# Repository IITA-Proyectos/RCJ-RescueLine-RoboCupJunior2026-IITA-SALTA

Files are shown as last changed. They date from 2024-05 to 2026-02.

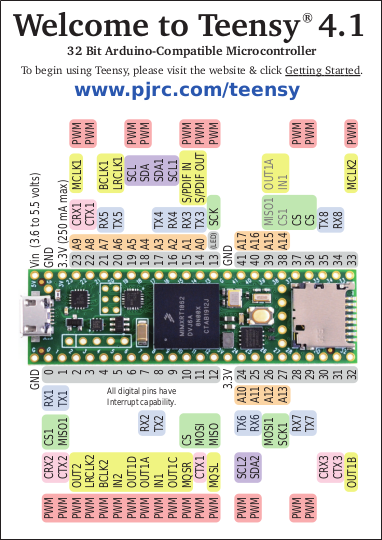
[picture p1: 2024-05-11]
Hardware/ELECTRONICA/imagenes/image.png

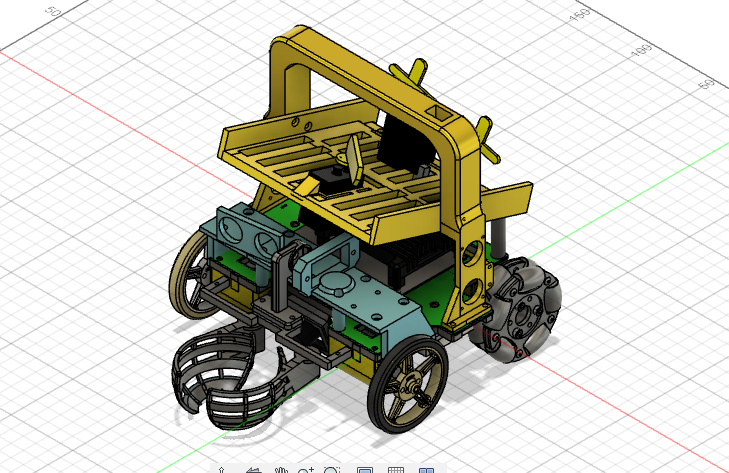
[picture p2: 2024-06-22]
Hardware/CAD/Imagenes/Rescuebot.png

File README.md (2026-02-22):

---
# Welcome to the Github account of the robotics team from IITA Salta (Argentina).
--- 
pixelcut-export (1)
## Competition info
The team is preparing for the **'Roboliga'** competition in the Rescue Line category. The Roboliga Rescue Line competition challenges teams of autonomous robots to navigate skillfully through a physical environment that simulates disaster scenarios. Equipped with sensors and programming skills, the robots must follow a line marked on rough terrain, avoiding obstacles and performing tasks such as detecting simulated victims. This competition not only tests robots' ability for autonomous navigation and environmental perception but also assesses the effectiveness of mechanical design strategies and motion control
## About us

|  |  |
|-----:|---|
|Team name | IITA SALTA- RescueBot  |
|School | Instituto de Innovacion y Tecnologia Aplicada |
|Country | Argentina |

**Mentors:**

- **Mr. Gustavo Viollaz**: 
He is the team director, and he helps with delivering or ordering the needed parts for our robot. He also gives good advice and tips on how to assemble the robot. Additionally, our director also gives us directions when needed.
- **Mr. Enzo Juarez**:
He is the team mentor and has been involved in our robotics projects for several years. He is an electronic technician, and his specialty is programming. He always helps us when we have problems.

**Members:**

- **Benjamin Villagran**:
  He is in charge of the electronics part of our robot and the programming in python.

- **Lucio Saucedo**:
  He is in charge of programming in Python and handling the Raspberry Pi integration.

- **Laureano Monteros**:
  He is in charge of programming in C++ and handling the Teensy integration.

## Our School
pixelcut-export (1)
  <p align="left">
  



  
  </p>

**Buenos Aires 135, oficina 102**

## Our Robot
All important hardware and software information and notes are stored on this Github. Use these docs as the main index:

- [Vision + YOLO](rpi/YOLO%20y%20Raspberry.md) - Pipeline de vision, modelos y reglas 2026 de rescate.
- [Raspberry <-> Teensy Communication](rpi/Comunicacion%20de%20la%20raspberry%20y%20la%20teensy.md) - Protocolo serial.
- [Pendientes (unificado)](pendientes/pendientes_generales.md) - Estado actual y tareas.

## Raspberry requirements

Instalar dependencias de Python usadas por `rpi/final_rpi/Main.py`:

```bash
pip install -r rpi/requirements.txt
```

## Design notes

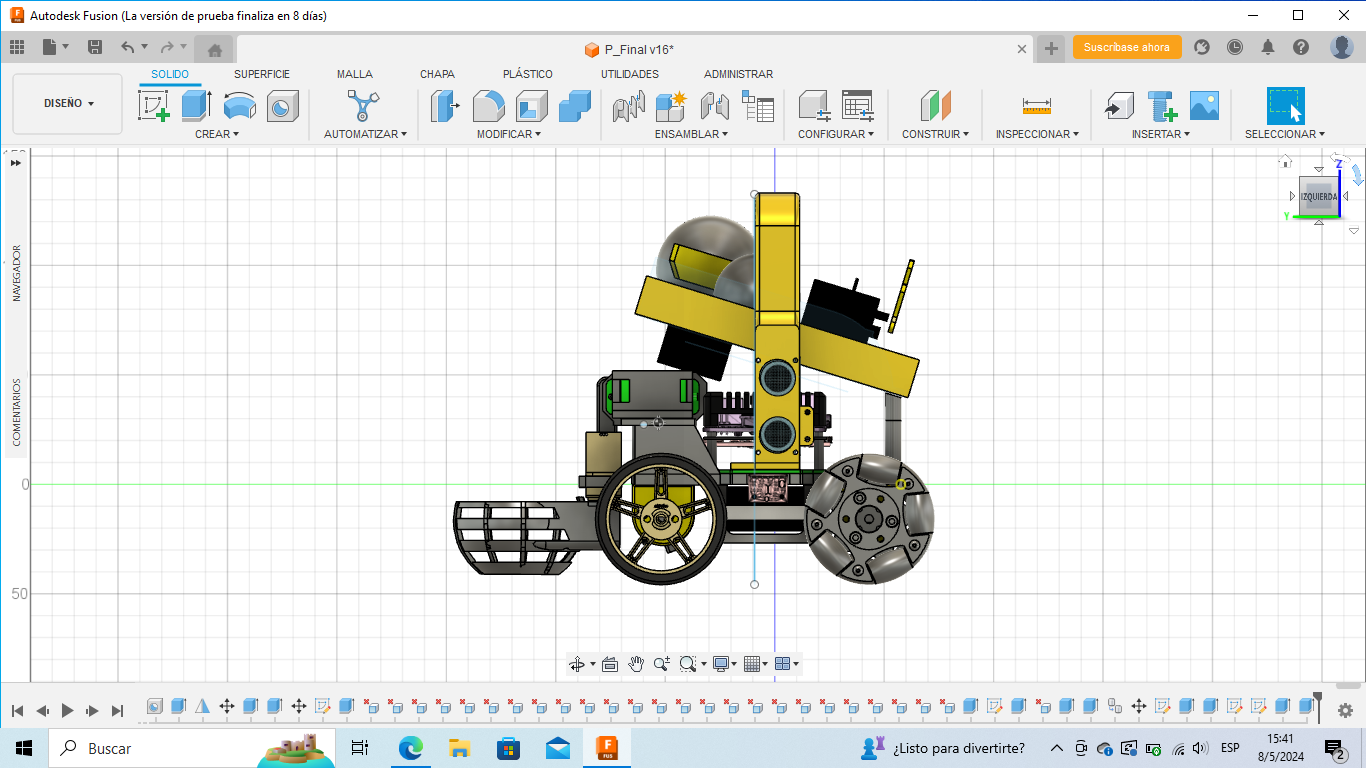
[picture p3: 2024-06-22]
Hardware/CAD/Imagenes/left.png

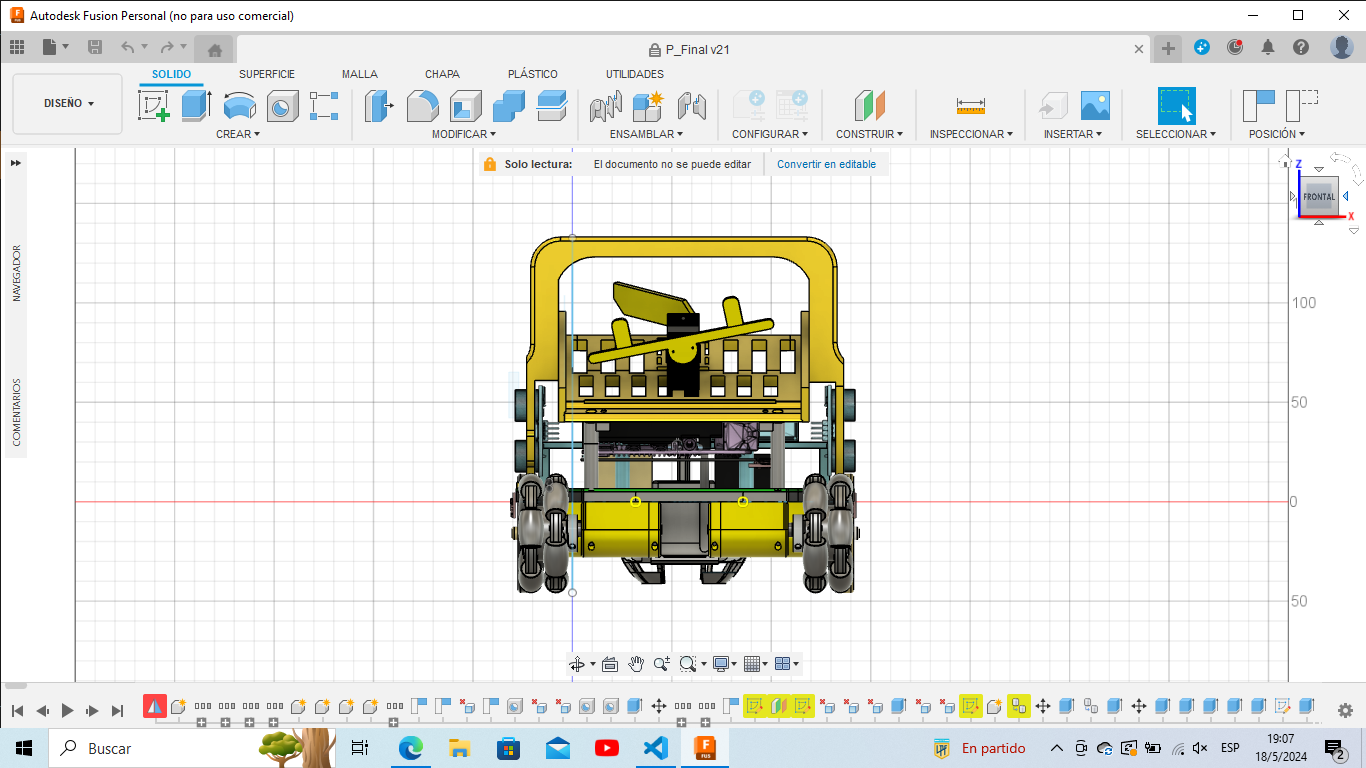
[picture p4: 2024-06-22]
Hardware/CAD/Imagenes/back.png

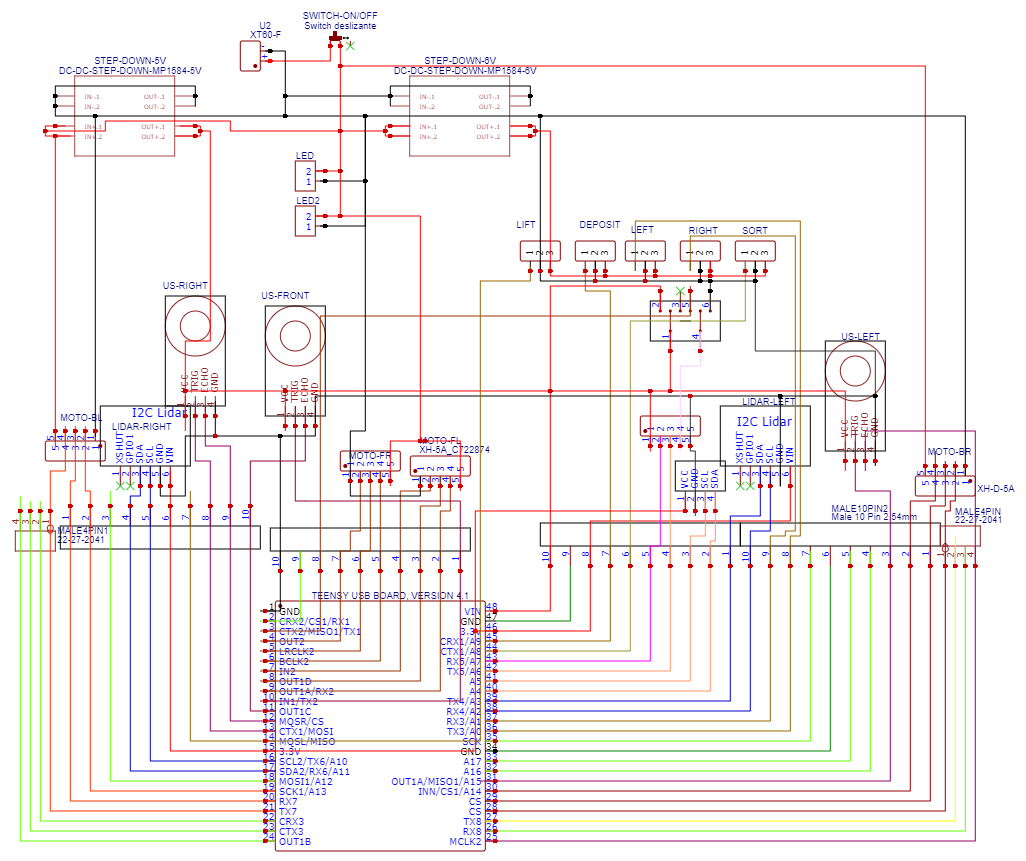
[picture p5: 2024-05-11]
Hardware/ELECTRONICA/imagenes/Schematic_Trabajo-roboliga_2024-05-02.png

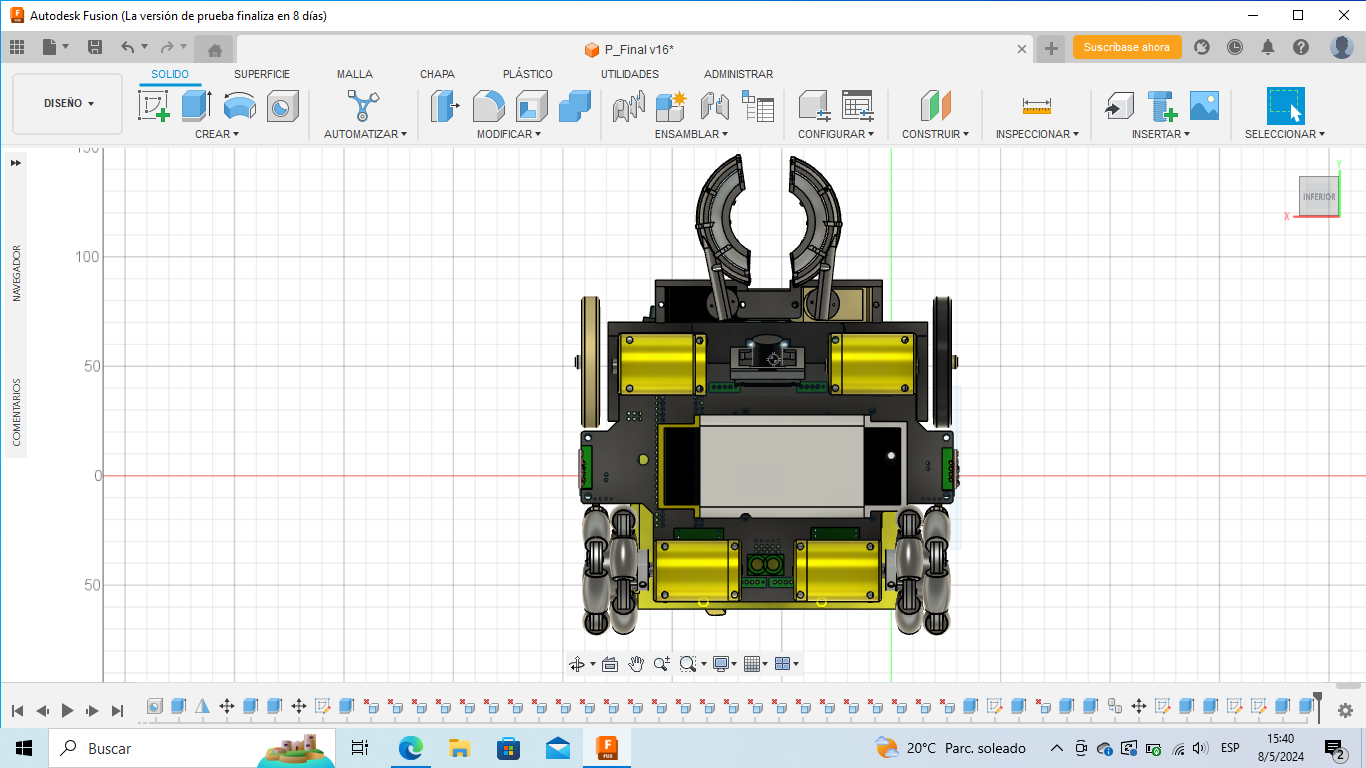
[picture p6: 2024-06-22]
Hardware/CAD/Imagenes/inferior.png

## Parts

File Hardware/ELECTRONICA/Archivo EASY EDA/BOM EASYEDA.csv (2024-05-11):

Name | Designator | Quantity
DC-DC-STEP-DOWN-MP1584-5V | STEP-DOWN-5V | 1
DC-DC-STEP-DOWN-MP1584-6V | STEP-DOWN-6V | 1
GYVL53L0X corrected | LIDAR-LEFT,LIDAR-RIGHT | 2
XH-5A_C722874 | MOTO-FL | 1
MOTO-BL | MOTO-BL | 1
XH-D-5A | MOTO-BR,MOTO-FR | 2
XT60-F | U2 | 1
Header-Female-2.54_1x3 | DEPOSIT,LEFT,LIFT,RIGHT,SORT | 5
Raspberry | RASP | 1
HUELLA_RASPBERRY_4 | U6 | 1
SOPORTE BATERIA | U7 | 1
1x2 Male Pin Header | LED,LED2 | 2
Male 10 Pin 2.54mm | MALE10PIN,MALE10PIN1,MALE10PIN2,MALE-10PIN | 4
22-27-2041 | MALE4PIN,MALE4PIN1 | 2
MPU6050 4pin | MPU6050 | 1
Toggle Switch DPDT 6 Pins 3 Positions ON/OFF/ON | SWITCH-6PIN | 1
Switch deslizante | SWITCH-ON/OFF | 1
TEENSY USB BOARD, VERSION 4.1 | U1 | 1
JSN | US-LEFT,US-RIGHT,US-FRONT | 3

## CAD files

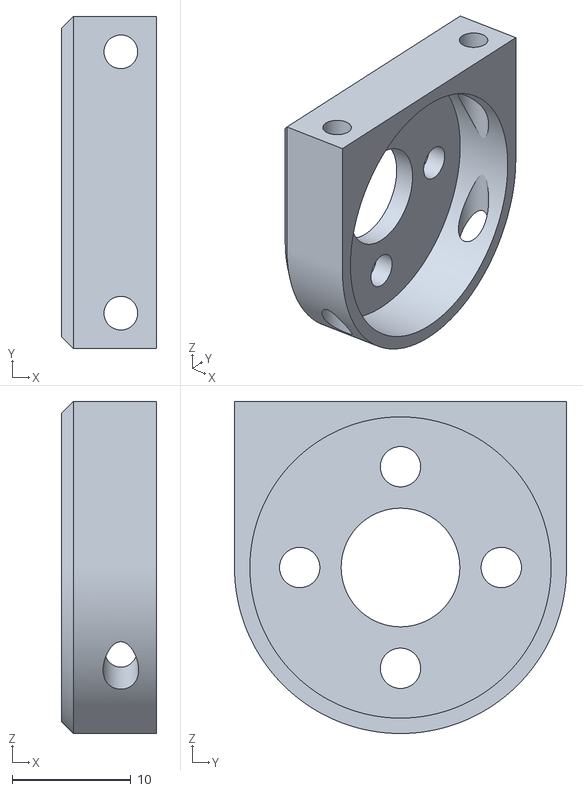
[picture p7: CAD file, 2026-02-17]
Hardware/CAD/STLS/motormount v2.stl
8.00 x 28.0 x 28.0

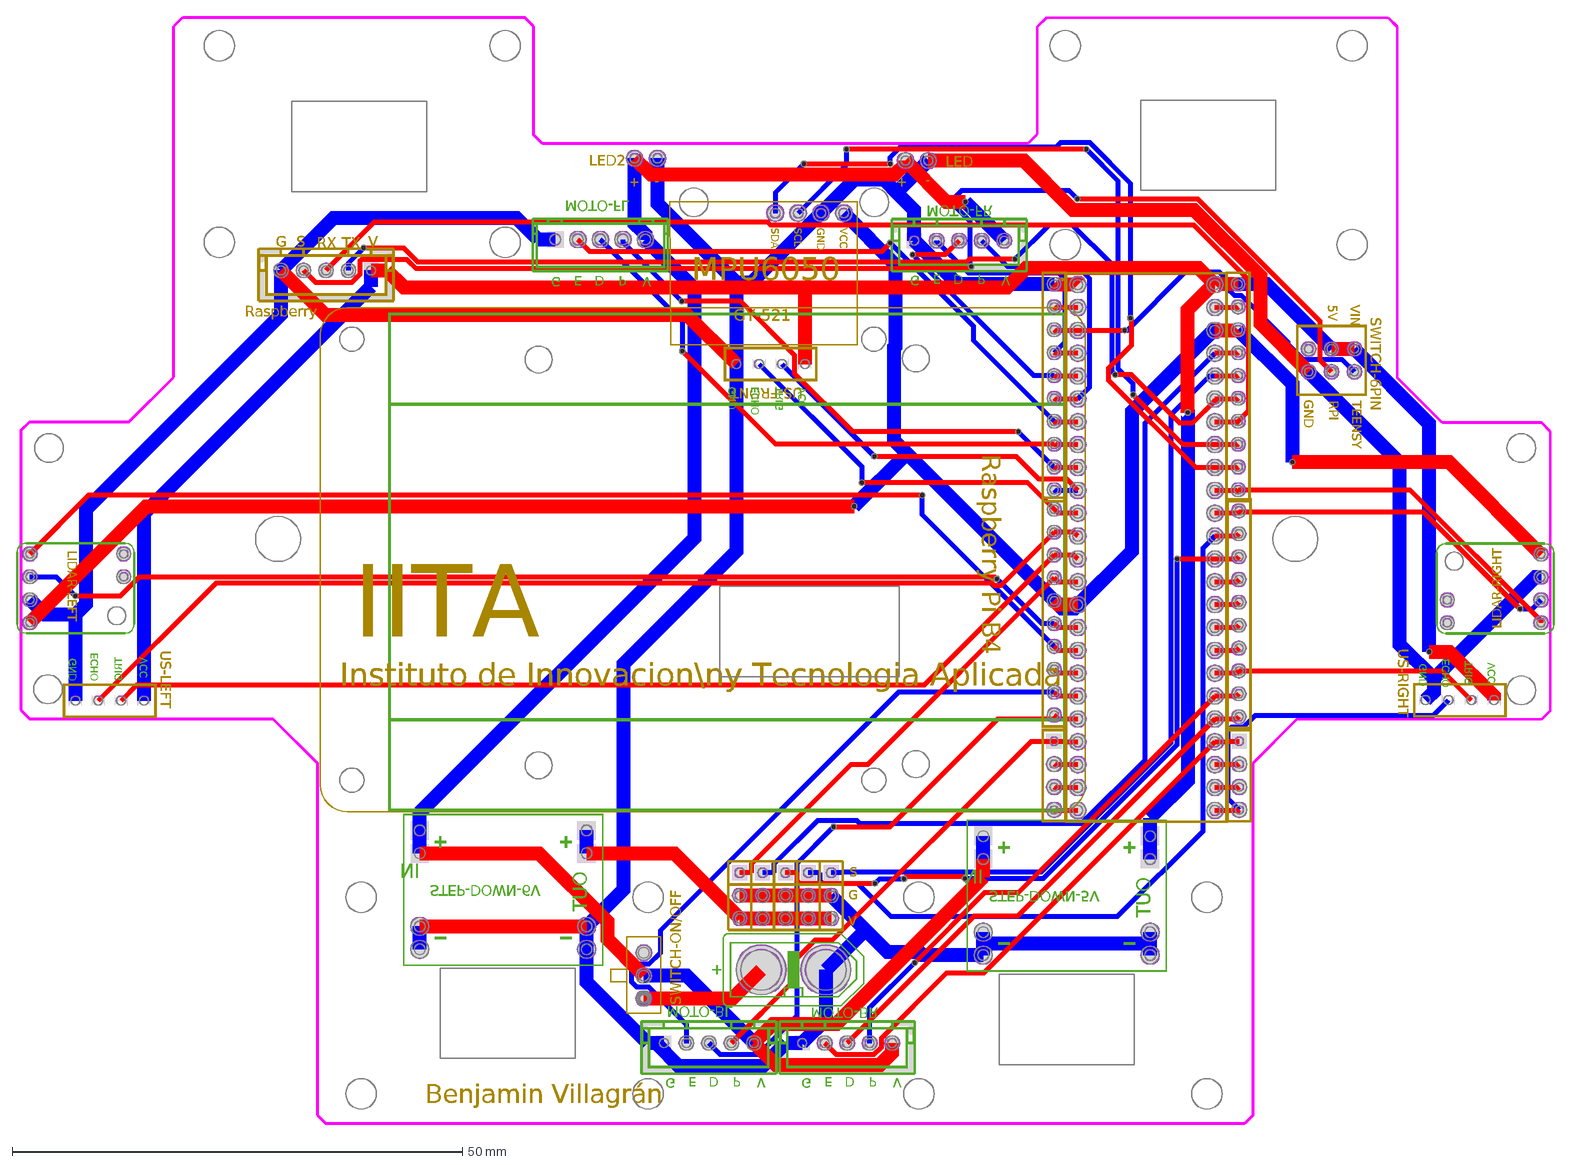
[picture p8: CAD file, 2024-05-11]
Hardware/ELECTRONICA/AUTOCAD PCB/BOCETO DE PCB.dxf
G
V
E
D
P
VIN
TEENSY
GND
RPI
5V
-
+
S
Instituto de Innovacion\ny Tecnologia Aplicada
IITA
TX
RX
Benjamin Villagrán
STEP-DOWN-5V
IN
OUT
STEP-DOWN-6V
LIDAR-LEFT
GPIO1
XSHUT
SDA
SCL
LIDAR-RIGHT
MOTO-FL
MOTO-BL
MOTO-FR
MOTO-BR
Raspberry
Raspberry Pi B4
LED
LED2
MPU6050
VCC
GY-521
SWITCH-6PIN
SWITCH-ON/OFF
US-LEFT
TRIG
ECHO
US-RIGHT
US-FRONT

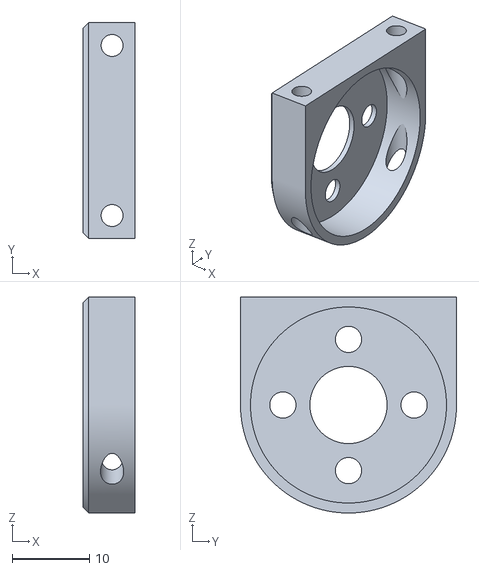
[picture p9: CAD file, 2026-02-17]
Hardware/CAD/STLS/motormount v2 thin.stl
6.80 x 28.0 x 28.0

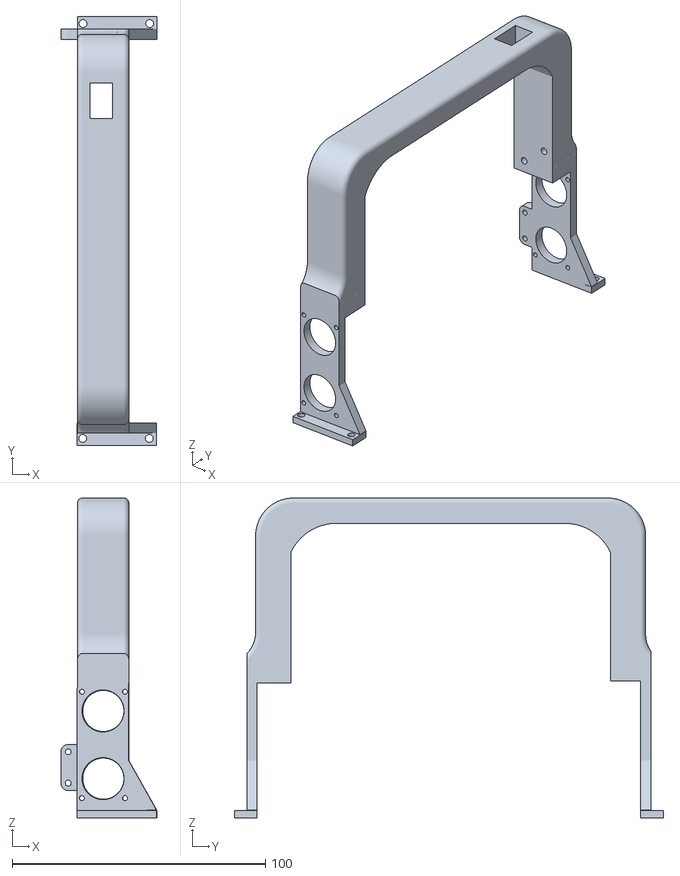
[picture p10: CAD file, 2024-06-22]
Hardware/CAD/STLS/ultrasoniDOS.stl
37.9 x 169.4 x 126.3

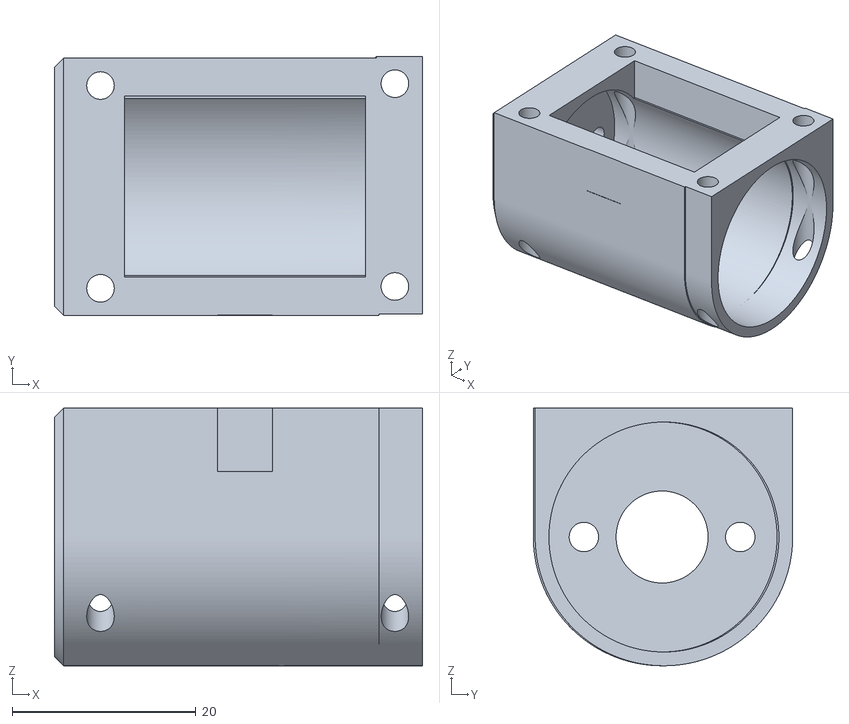
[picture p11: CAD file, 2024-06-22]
Hardware/CAD/STLS/SoporteMotorDelantero.stl
40.0 x 28.2 x 28.0

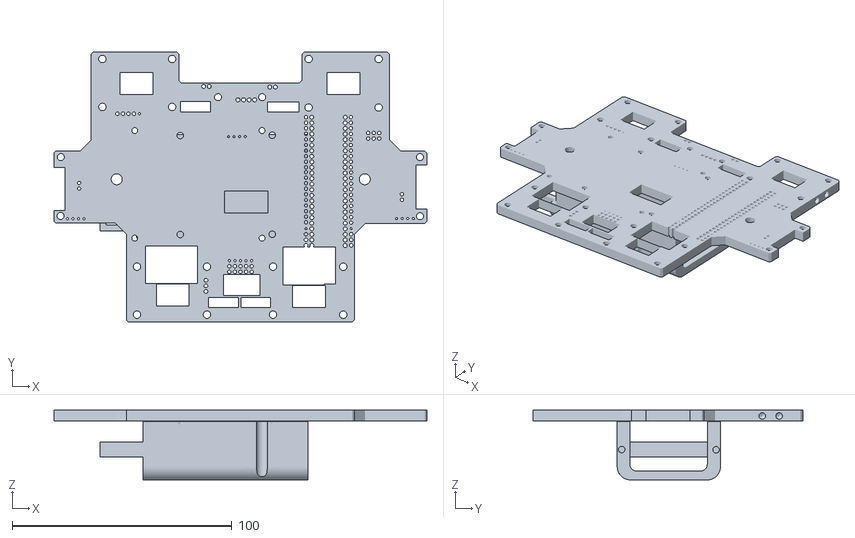
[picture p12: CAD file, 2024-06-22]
Hardware/CAD/STLS/Base.stl
169.9 x 122.9 x 31.8

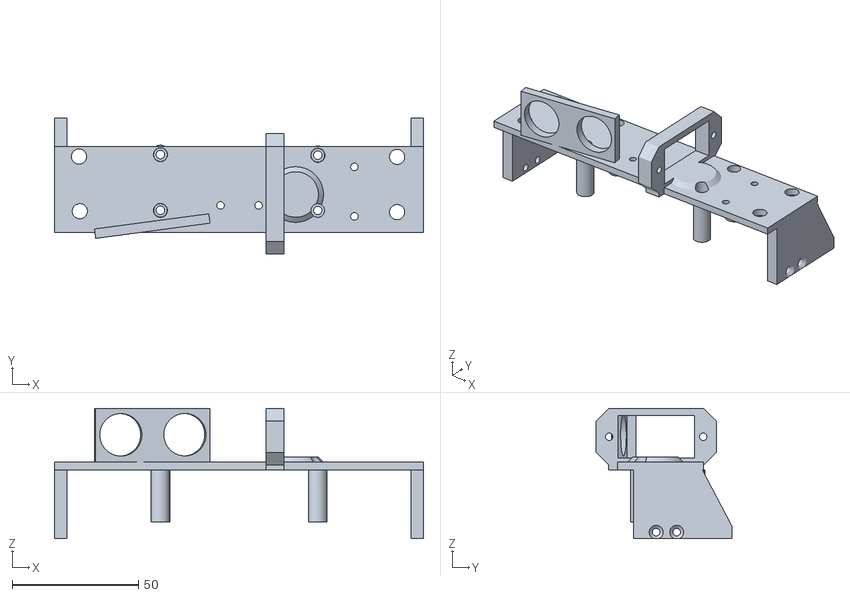
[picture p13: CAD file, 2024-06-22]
Hardware/CAD/STLS/Servos_corregido.stl
146.0 x 53.8 x 51.6

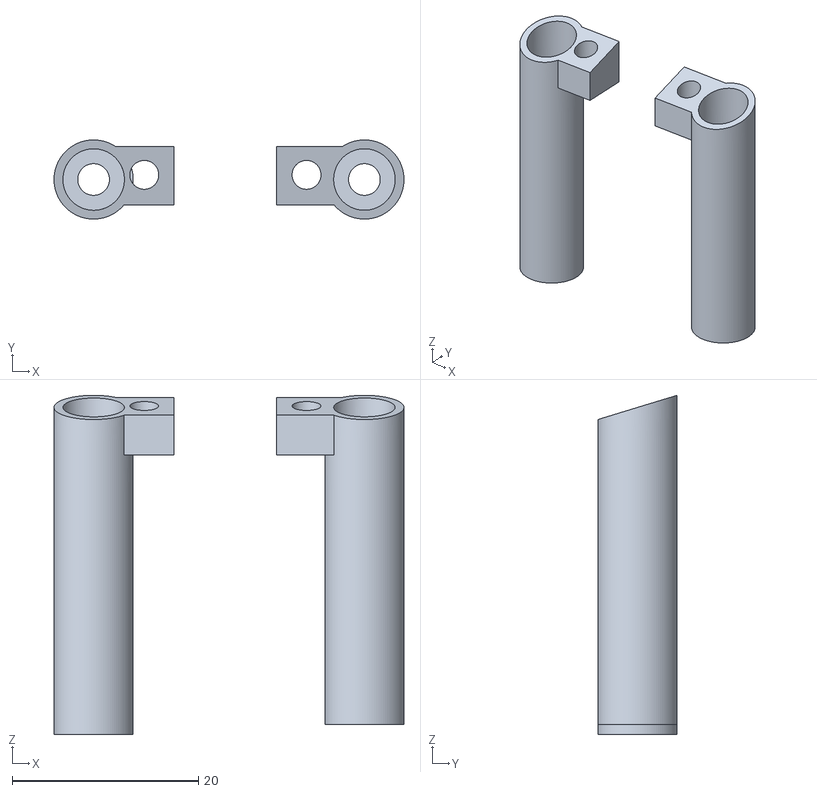
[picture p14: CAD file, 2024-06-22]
Hardware/CAD/STLS/Tubitos_juntos.stl
37.6 x 8.50 x 36.4

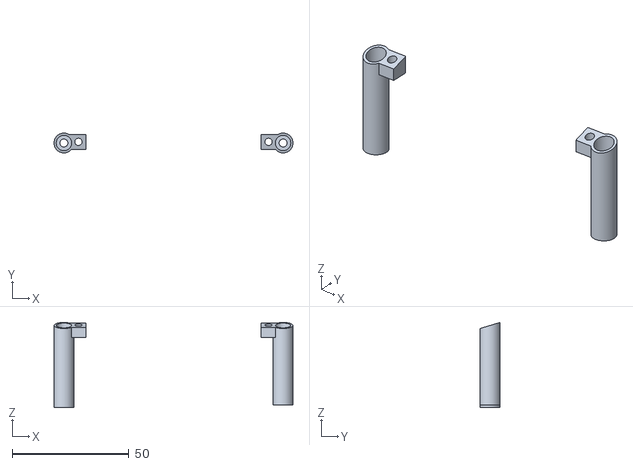
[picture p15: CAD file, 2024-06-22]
Hardware/CAD/STLS/Tubitos_6diam.stl
102.3 x 8.50 x 36.4

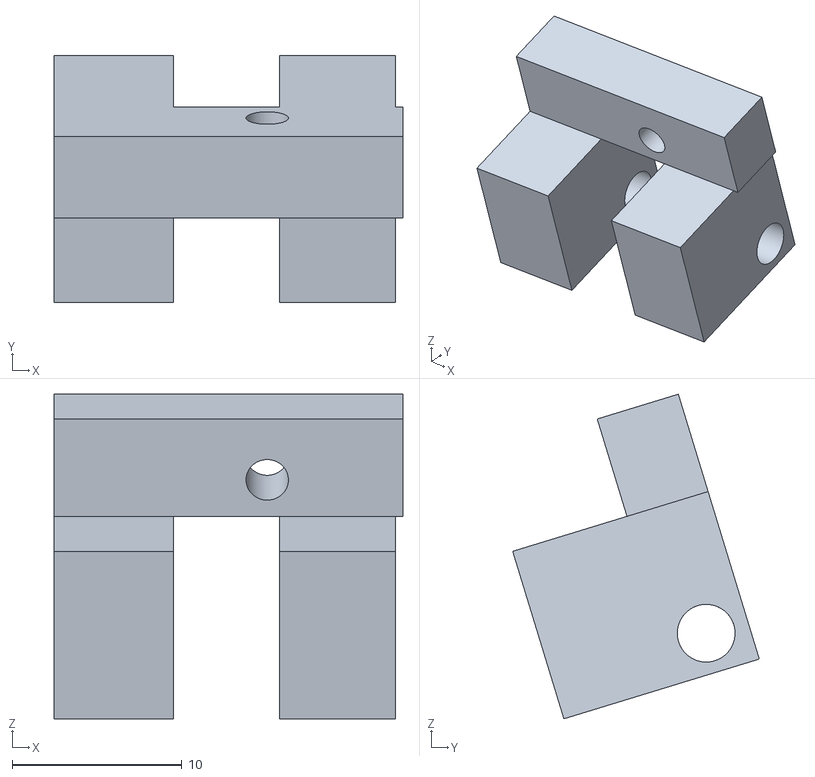
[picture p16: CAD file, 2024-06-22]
Hardware/CAD/STLS/enganche.stl
20.6 x 14.5 x 19.1

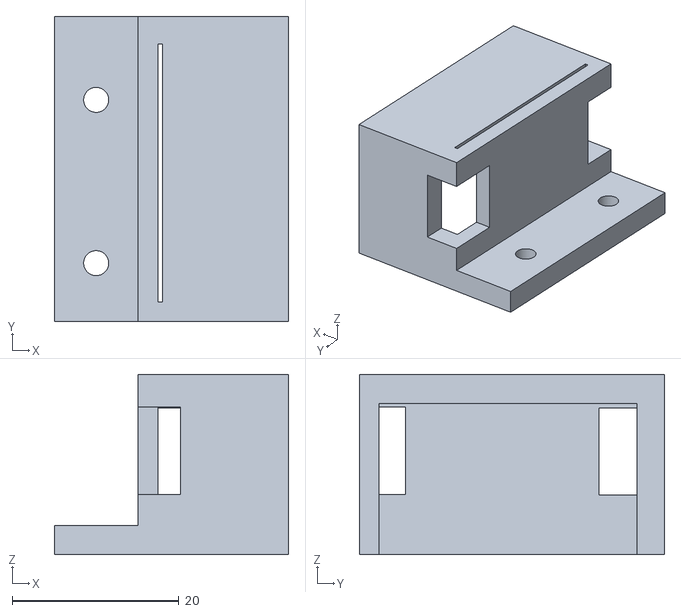
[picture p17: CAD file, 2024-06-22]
Hardware/CAD/STLS/casco de servo.stl
28.1 x 36.6 x 21.7

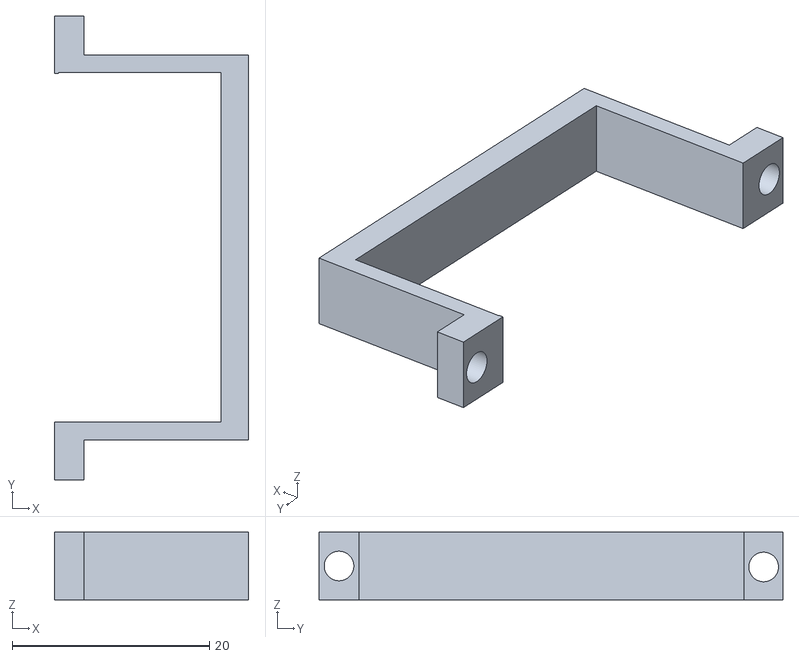
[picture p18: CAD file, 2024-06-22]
Hardware/CAD/STLS/agarra_bateria.stl
19.7 x 47.0 x 6.85

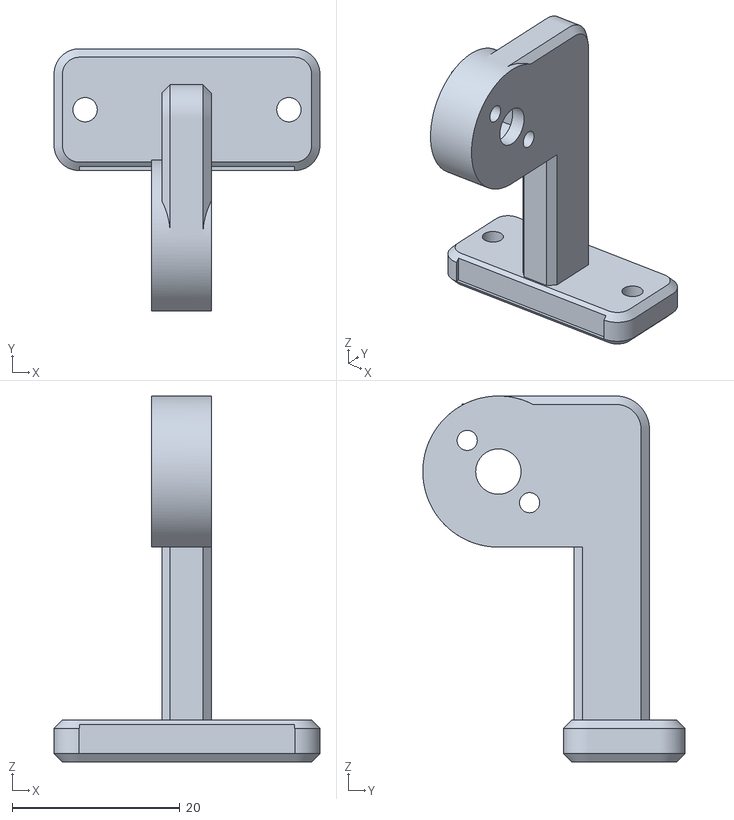
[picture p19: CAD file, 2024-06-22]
Hardware/CAD/STLS/Extensión_servo.stl
31.7 x 31.2 x 43.6

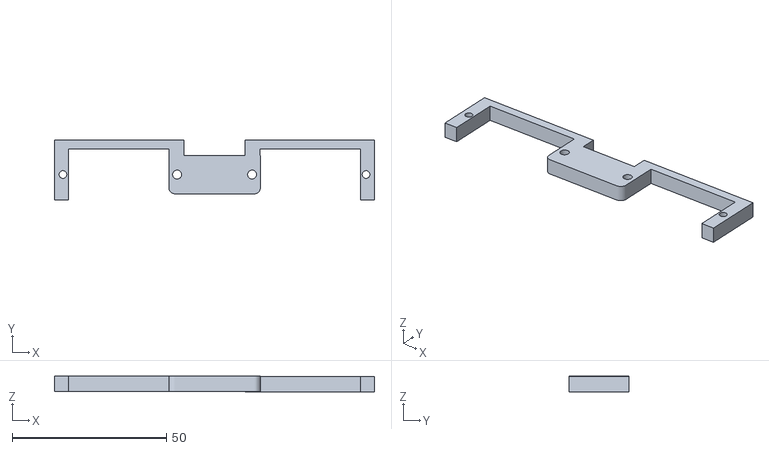
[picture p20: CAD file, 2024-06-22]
Hardware/CAD/STLS/brazo_servos.stl
103.6 x 19.5 x 5.08

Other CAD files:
Hardware/CAD/STLS/carcasa_rapsberry.stl
Hardware/CAD/STLS/Soprte-de-camara.stl
Hardware/CAD/STLS/Motor_L_corregido.stl
Hardware/CAD/STLS/BASE CAJITA.stl
Hardware/CAD/STLS/Aleta(izquierda).stl
Hardware/CAD/STLS/Aleta.stl
Hardware/CAD/STLS/controlador_pelotas.stl
Hardware/CAD/STLS/pala.stl

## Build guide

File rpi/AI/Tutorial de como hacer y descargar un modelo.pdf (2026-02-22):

## CREACIÓN MODELO ENTRENADO CON IA

En esta documentación aprenderás a crear y entrenar un modelo de inteligencia artificial (IA) desde cero para la detección de objetos. Aprenderás todo el flujo de trabajo, desde la creación del dataset, pasando por el entrenamiento del modelo, hasta su uso en código para detectar objetos en imágenes o video en tiempo real.

El objetivo de este tutorial es que, al finalizar, puedas:

- Tener un dataset correctamente anotado y preprocesado.
- Entrenar un modelo de detección de objetos utilizando Roboflow
- Descargar el modelo entrenado y usarlo en tus proyectos, por ejemplo en robots o sistemas de visión.

¿Qué es Roboflow?

Roboflow es una plataforma en la nube que permite a a crear, organizar y entrenar datasets de manera fácil. Con Roboflow se pueden:

- Subir imágenes y anotarlas para tareas
de detección de objetos, clasificación o
segmentación.
- Exportar el dataset en formatos compatibles con frameworks populares como YOLO, TensorFlow, PyTorch y ONNX.
- Entrenar modelos directamente en la
nube o descargar el dataset para

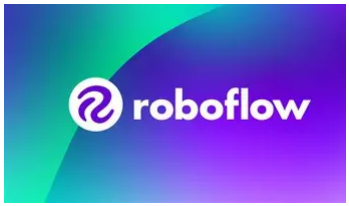
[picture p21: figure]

entrenarlo localmente (es lo que vamos a hacer)

### Creación y entrenamiento de un modelo con Roboflow

Paso 1: Crear un proyecto en Roboflow

1. Ingresar a Roboflow y registrarse.
2. Hacer clic en “Create New Project”.
3. Seleccionar tipo de proyecto: Object Detection.
4. Poner un nombre al proyecto (por ejemplo: Roboliga 2025).
5. Elegir el formato de anotación (YOLO, COCO, etc.) y crear el proyecto.

Paso 2: Subir imágenes y etiquetar

1. Hacer clic en “Upload Images” dentro del proyecto.
2. Seleccionar las imágenes del dataset.
3. Asignar las clases o labels (por ejemplo: boxgreen, boxred, negro, plateado).
4. Revisar que los bounding boxes estén correctamente colocados.

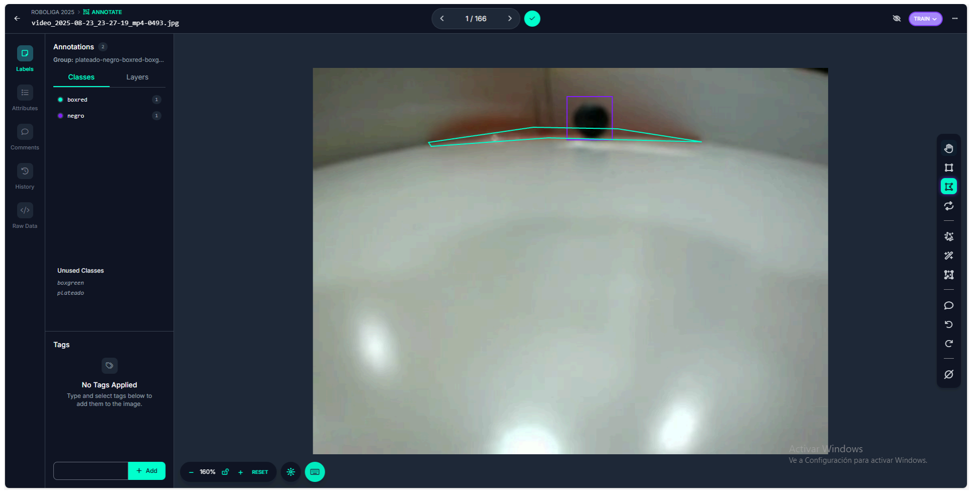
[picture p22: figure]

Paso 3: Generar dataset listo para entrenamiento

1. Dentro del proyecto, hacer clic en la opción indicada (la flecha en la imagen).

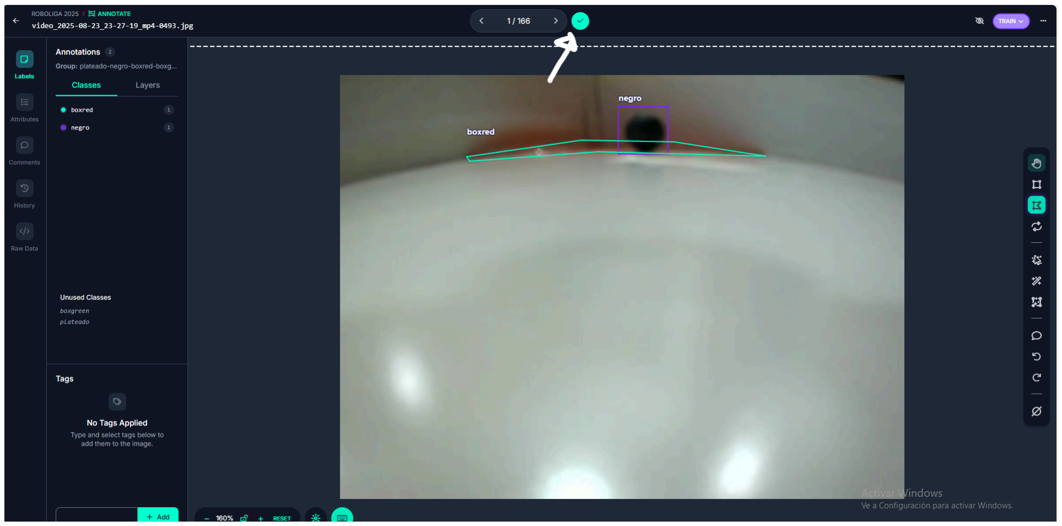
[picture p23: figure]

2. Esto añadirá al dataset final todas las imágenes que previamente revisaste y etiquetaste, garantizando que estén listas para el entrenamiento.

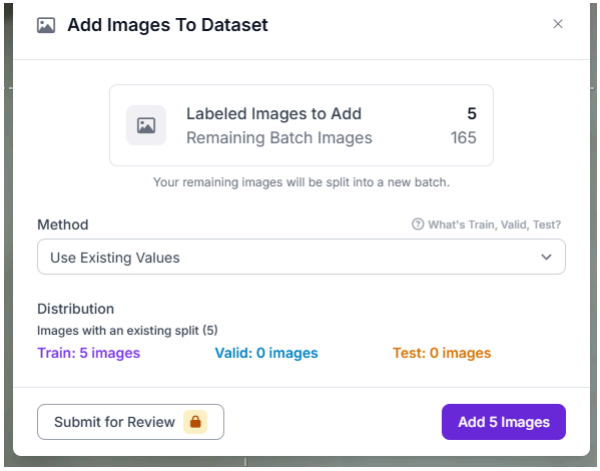
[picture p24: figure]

Paso 4: Entrenamiento en Roboflow

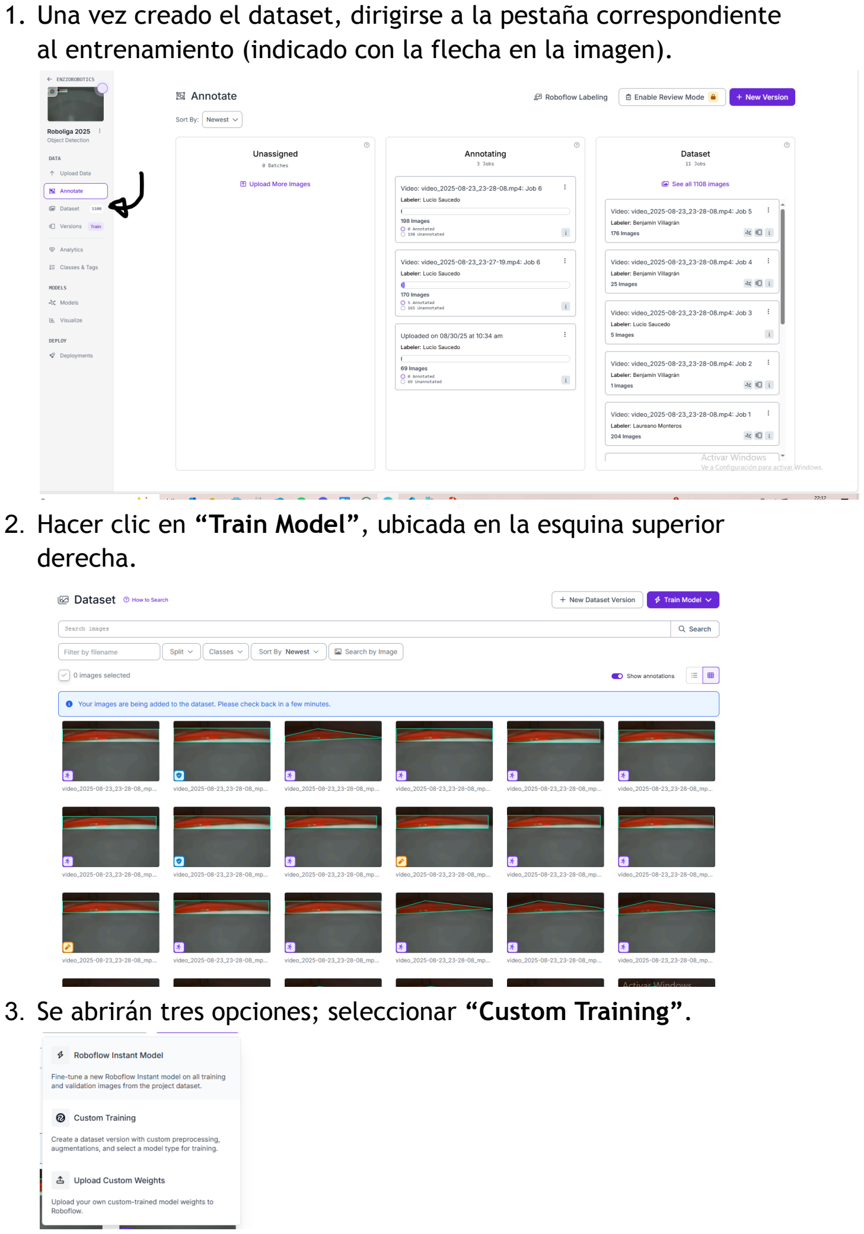
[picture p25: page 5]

1. Una vez creado el dataset, dirigirse a la pestaña correspondiente al entrenamiento (indicado con la flecha en la imagen).
2. Hacer clic en “Train Model”, ubicada en la esquina superior derecha.
3. Se abrirán tres opciones; seleccionar “Custom Training”.

4.Asignar un nombre a la versión del modelo que se va a crear.

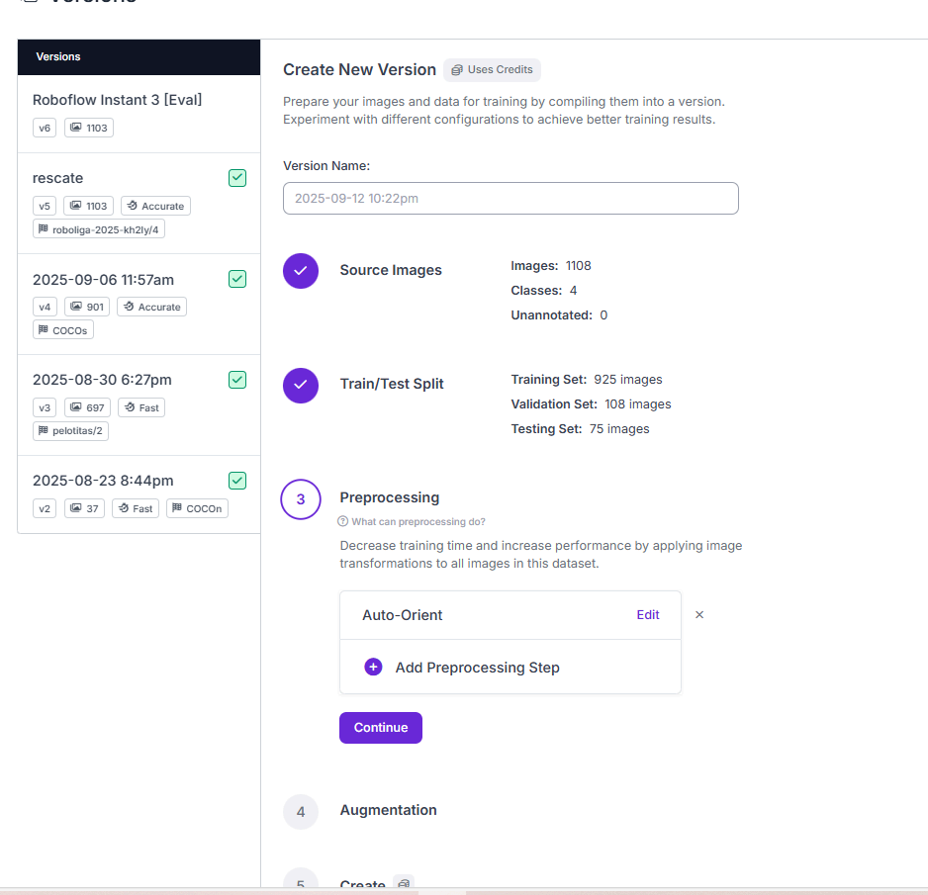
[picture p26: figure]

5. Seguir el asistente y hacer clic en “Continuar” hasta crear la versión del modelo.

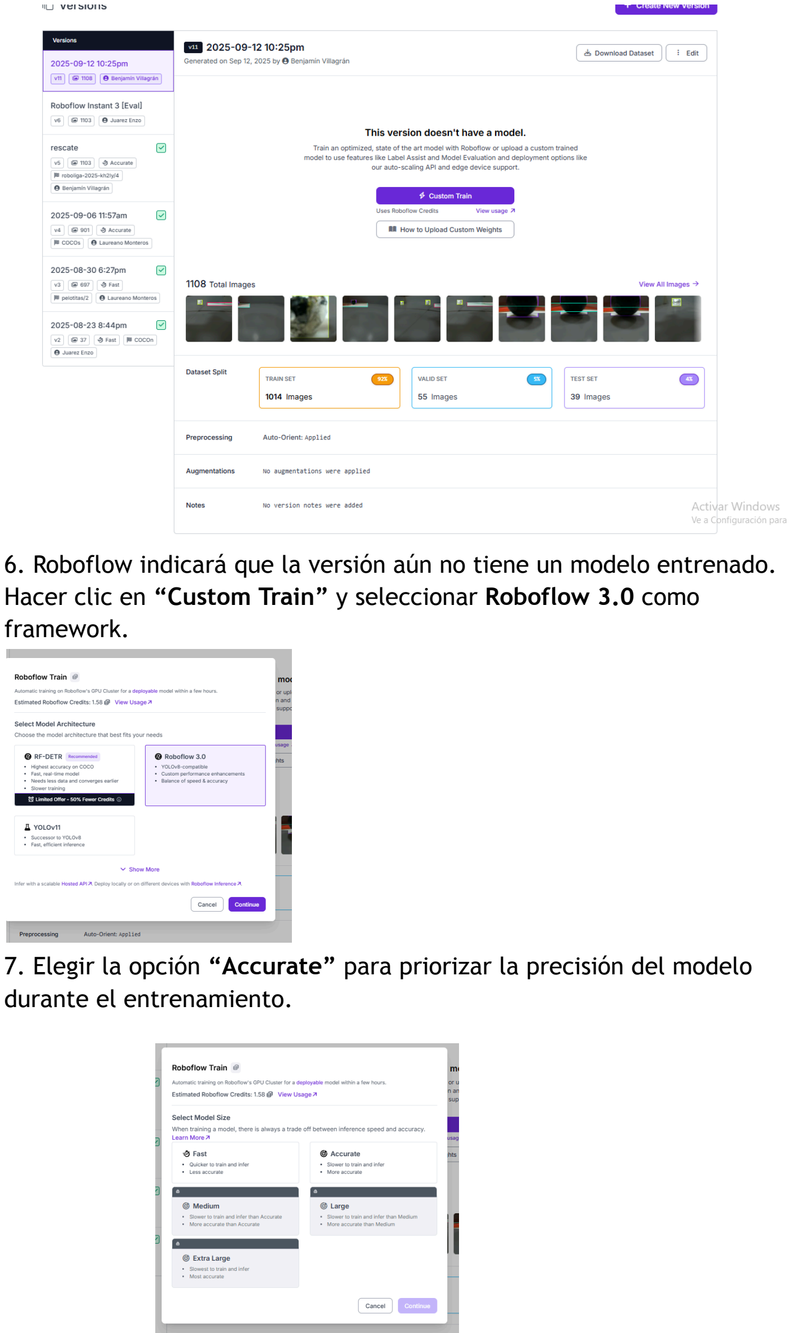
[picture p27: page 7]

6. Roboflow indicará que la versión aún no tiene un modelo entrenado. Hacer clic en “Custom Train” y seleccionar Roboflow 3.0 como framework.
7. Elegir la opción “Accurate” para priorizar la precisión del modelo durante el entrenamiento.

8.Tras configurar los parámetros, Roboflow comenzará a entrenar el dataset. El tiempo de entrenamiento dependerá del tamaño del dataset y de los recursos de la nube disponibles.

9.Una vez finalizado, dirigirse a la sección “Versions” para visualizar el modelo entrenado.

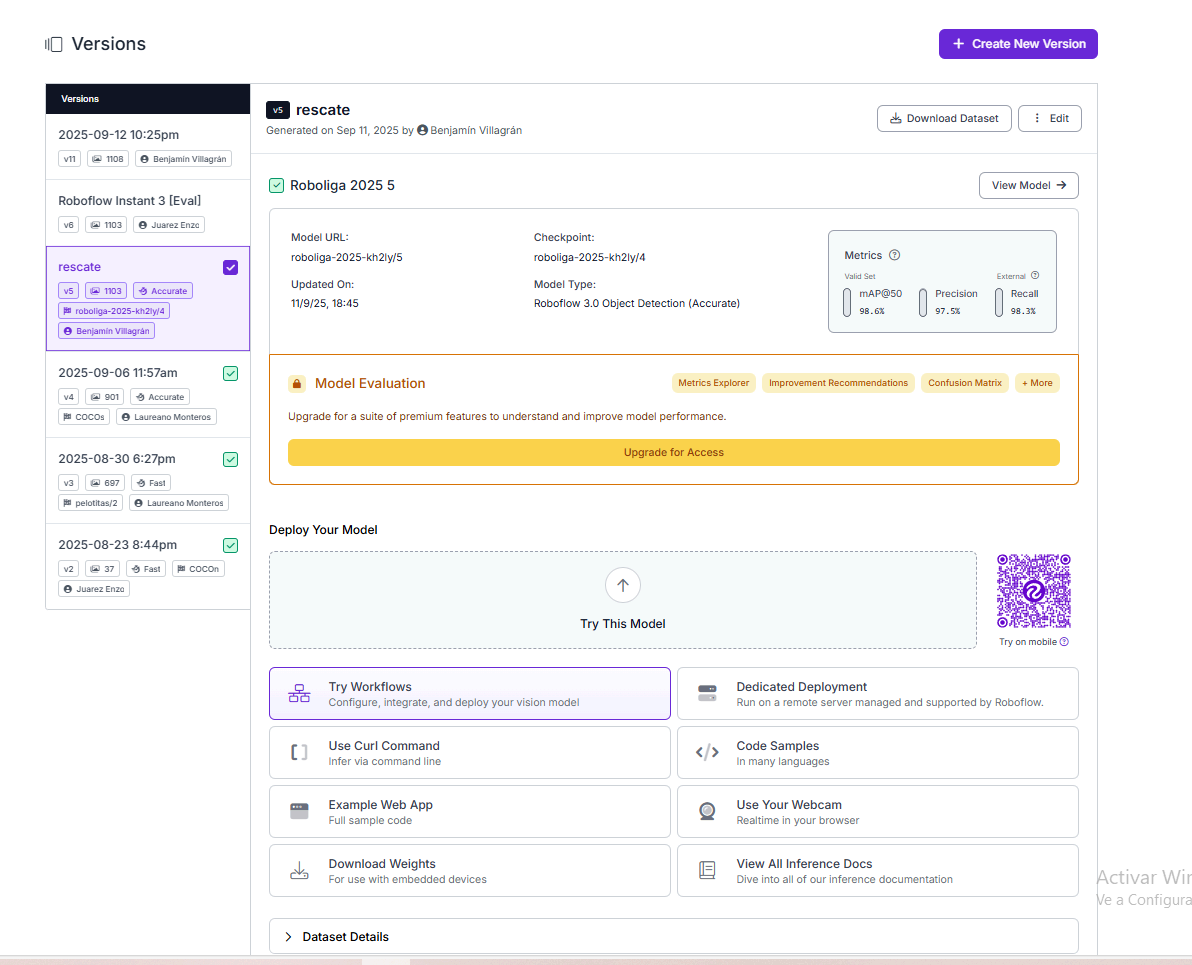
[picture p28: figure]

Nota: Roboflow no permite descargar el modelo entrenado de forma gratuita.

Para continuar trabajando localmente, se puede descargar el dataset con todas las anotaciones ya realizadas.
10. Hacer clic en “Download Dataset” y seguir el asistente haciendo clic en “Continuar”.

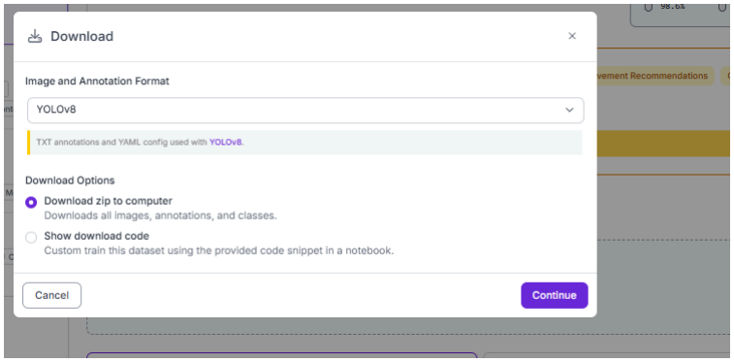
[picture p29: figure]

11. Esto permitirá usar el dataset para entrenar el modelo localmente con cualquier framework compatible, como YOLOv8 o PyTorch.

### Entrenamiento en Google Colab

Después de haber creado y preparado nuestro dataset en Roboflow, ahora vamos a dar el siguiente paso: entrenar nuestro modelo de detección de objetos utilizando Google Colab.

En esta etapa aprenderemos a:

1. Cargar el dataset descargado de Roboflow en Colab, que ya contiene todas las imágenes y etiquetas revisadas.
2. Configurar el entorno de entrenamiento, incluyendo la instalación de librerías necesarias como ultralytics.
3. Entrenar el modelo de manera sencilla y guiada.
4. Evaluar y guardar el modelo entrenado, listo para usarlo en proyectos locales, robots o aplicaciones de visión por

computadora.

Esta etapa aprovecha la potencia de procesamiento de Colab para entrenar modelos de manera eficiente, incluso si tu computadora local no tiene GPU.

### ¿Qué es Google Colab?

Google Colab (Colaboratory) es una plataforma gratuita de Google que permite escribir y ejecutar código en Python directamente desde el navegador, sin necesidad de instalar nada en tu computadora.

Sus principales ventajas son:

- Uso de GPU y TPU gratuitas: Ideal para entrenar modelos de inteligencia artificial y redes neuronales sin depender de la potencia de tu computadora local.
- Entorno en la nube:
Todos los archivos y
proyectos se pueden
guardar en Google
Drive, lo que facilita
acceder y compartir
los proyectos desde
cualquier lugar.
- Integración con
librerías de IA y
visión por
computadora: Se

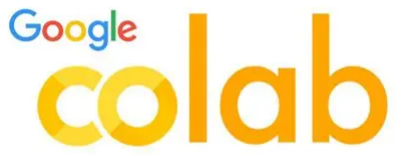
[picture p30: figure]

pueden instalar y usar frameworks como YOLOv8, TensorFlow, PyTorch, OpenCV, entre otros.

- Ideal para principiantes y profesionales: Permite experimentar con proyectos de IA sin necesidad de configuraciones complejas.

En este tutorial utilizaremos Colab para entrenar nuestro modelo de detección de objetos usando el dataset previamente creado en Roboflow, aprovechando su GPU para un entrenamiento rápido y eficiente.

### Tutorial: Entrenamiento del modelo en Google Colab

Paso 1: Abrir Google Colab

1. Ingresar a Google Colab. (http://colab.research.google.com)
2. Hacer clic en “Nuevo cuaderno” (New Notebook) para crear un proyecto vacío donde trabajaremos nuestro entrenamiento.

Paso 2: Configurar la GPU

1. Ir al menú “Entorno de ejecución” → “Cambiar tipo de entorno de ejecución”.

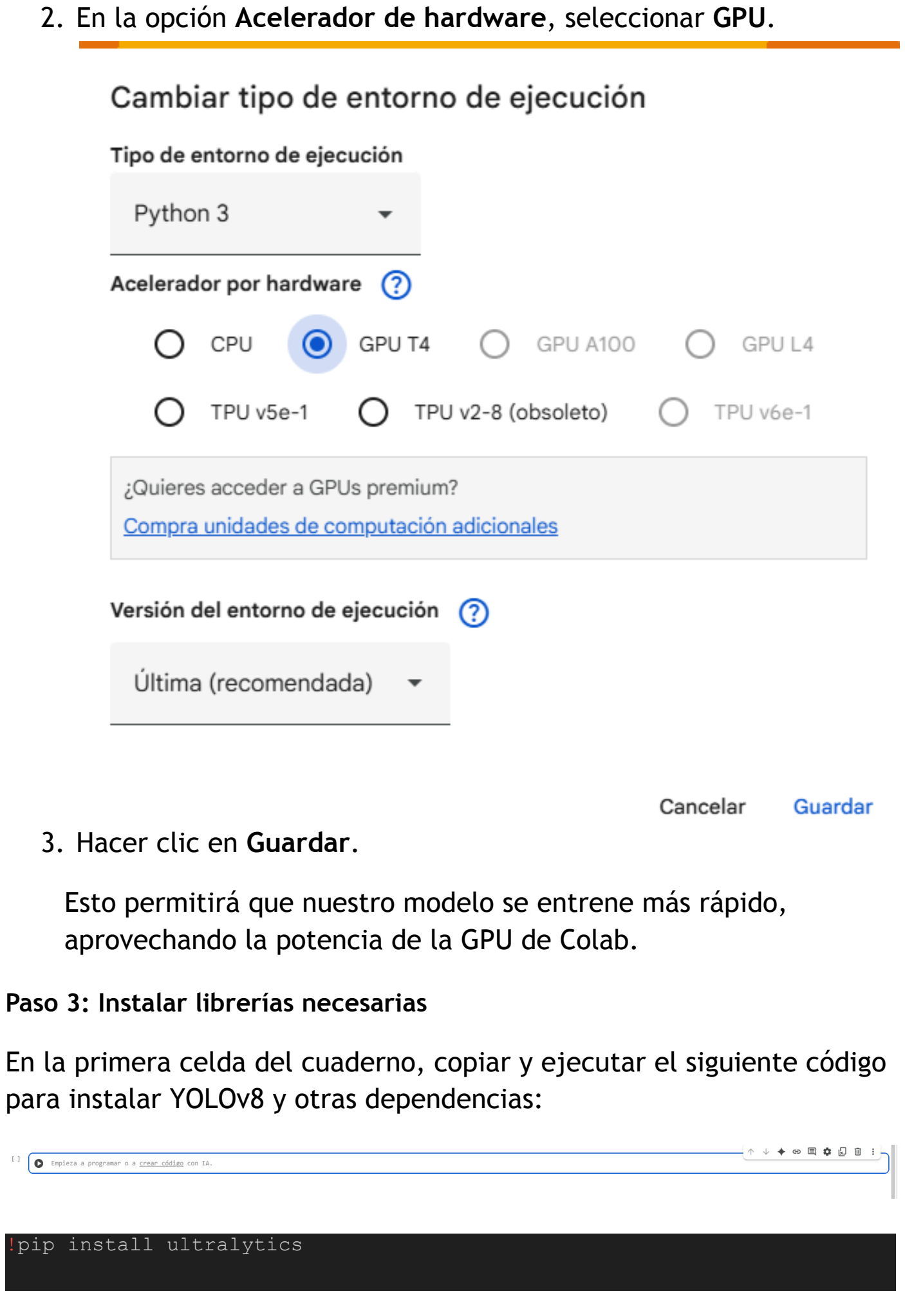
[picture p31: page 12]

2. En la opción Acelerador de hardware, seleccionar GPU.
3. Hacer clic en Guardar.

Esto permitirá que nuestro modelo se entrene más rápido, aprovechando la potencia de la GPU de Colab.

Paso 3: Instalar librerías necesarias

En la primera celda del cuaderno, copiar y ejecutar el siguiente código para instalar YOLOv8 y otras dependencias:

!pip install ultralytics

Esto instalará todo lo necesario para trabajar con nuestro dataset y entrenar el modelo.

Paso 4: Cargar y extraer el dataset en Google Colab

1. Subir el archivo ZIP de tu dataset descargado de Roboflow:

from google.colab import files

# Aparecerá un botón para seleccionar tu archivo ZIP

files.upload()

2. Una vez subido, extraer el contenido del ZIP a la carpeta dataset:

!unzip dataset.zip -d dataset

Esto creará una carpeta llamada dataset con todas las imágenes y etiquetas listas para entrenar el modelo.

Paso 5: Entrenar el modelo

from ultralytics import YOLO

# Cargar un modelo YOLOv8 base (ej. yolov8n.pt)

model = YOLO("yolov8n.pt")

# Entrenar el modelo usando el dataset extraído

model.train(data="dataset/data.yaml", epochs=50)

Asegúrate de que dentro del ZIP exista el archivo data.yaml que indica las rutas de imágenes y etiquetas. Ten en cuenta que si no seleccionaste la opcion de GPU tardara horas en cambio si la seleccionaste tardara mucho menos tiempo

Paso 6: Descargar y probar el modelo entrenado

1. Una vez finalizado el entrenamiento, el modelo se guarda automáticamente en:

runs/detect/train/weights/best.pt

2. Para descargarlo a tu computadora, ejecutar en Colab:

from google.colab import files

files.download("runs/detect/train/weights/best.pt")

Esto abrirá un cuadro de diálogo para guardar el archivo.

3. Este archivo .pt contiene el modelo entrenado y puede ser usado para:
- Inferencia en tu computadora local.
- Integración en un robot o proyecto de visión por computadora.
- Exportarlo a otros formatos (ONNX, CoreML, etc.) si lo necesitás.

### Consideraciones para Raspberry Pi

El archivo .pt que descargamos contiene el modelo completo entrenado y funciona muy bien en una computadora con GPU potente.

Sin embargo, en una Raspberry Pi:

- La potencia de procesamiento es limitada.
- El modelo .pt puede ser muy pesado y generar baja velocidad de inferencia.
- Esto puede causar que el robot o la aplicación se vuelva lenta o no pueda procesar video en tiempo real.

Solución:
Para usar el modelo en dispositivos con recursos limitados, como la Raspberry Pi, es recomendable convertirlo a un formato más ligero, por ejemplo:
- ONNX (.onnx): Permite usar el modelo con librerías optimizadas para ARM.

En el próximo paso veremos cómo exportar nuestro modelo .pt a ONNX, lo que permitirá ejecutar la detección en la Raspberry Pi de manera más eficiente.

### Paso 7: Exportar el modelo a ONNX para Raspberry

Pi

Para que nuestro modelo funcione de manera eficiente en dispositivos con recursos limitados como la Raspberry Pi, lo convertiremos a ONNX, un formato más ligero y compatible con frameworks optimizados para ARM.

### 1. Exportar el modelo entrenado

Después de entrenar tu modelo y tener best.pt, ejecuta la siguiente celda en Colab:

from ultralytics import YOLO

# Cargar el modelo entrenado

model = YOLO("runs/detect/train/weights/best.pt")

# Exportar a ONNX

model.export(format="onnx")

Esto creará un archivo best.onnx en la misma carpeta donde se encuentra tu .pt.

### 2. Descargar el modelo ONNX a tu computadora

from google.colab import files

# Descargar el archivo ONNX

files.download("runs/detect/train/weights/best.onnx")

Ahora tienes tu modelo en formato ONNX, listo para ser transferido a la Raspberry Pi.

### Probando el modelo en la Raspberry Pi

Una vez que hayas descargado tu modelo entrenado (.onnx) desde Google Colab, ya estás listo para probarlo en tu Raspberry Pi.

### 1. Instalar librerías necesarias

Antes de ejecutar el código, asegúrate de tener estas librerías instaladas en tu Raspberry Pi:

sudo apt update

sudo apt install -y python3-pip libatlas-base-dev

pip3 install --upgrade pip

pip3 install ultralytics numpy

pip3 install opencv-python

### 2. Código de ejemplo para probar el modelo

import cv2
import numpy as np from ultralytics import YOLO

# ---- CONFIG ----

MODEL_PATH = "/home/pi/Desktop/roboliga.onnx" # ruta de tu modelo VIDEO_PATH = 0 # 0 = cámara por defecto, o ruta de un video SCORE_THRESHOLD = 0.4
CLASS_NAMES = ['boxgreen', 'boxred', 'negro', 'plateado']

# ---- cargar modelo ----

model = YOLO(MODEL_PATH)
print("Modelo cargado correctamente.")

# ---- abrir cámara o video ----

cap = cv2.VideoCapture(VIDEO_PATH)
if not cap.isOpened():
raise SystemExit("No se pudo abrir la cámara o video")

while True:
ret, frame = cap.read()
if not ret:
break

# ---- detección ----

results = model.predict(frame, conf=SCORE_THRESHOLD, verbose=False)

# ---- dibujar bounding boxes ----

for res in results:
for box in res.boxes:
cls_id = int(box.cls[0])
score = float(box.conf[0])
x1, y1, x2, y2 = map(int, box.xyxy[0].cpu().numpy()) if hasattr(box.xyxy[0], "cpu") else map(int, box.xyxy[0]) label = f"{CLASS_NAMES[cls_id]} {score:.2f}"
color = (0, 255, 0)
cv2.rectangle(frame, (x1, y1), (x2, y2), color, 2) cv2.putText(frame, label, (x1, y1-5), cv2.FONT_HERSHEY_SIMPLEX, 0.5, color, 2)

# ---- mostrar ----

cv2.imshow("Detección ONNX", frame) if cv2.waitKey(1) & 0xFF == ord('q'): break

cap.release()
cv2.destroyAllWindows()

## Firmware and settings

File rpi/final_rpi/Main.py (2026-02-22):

import cv2
from camthreader import *
import numpy as np
import math
import time
import serial
import sys


debugOriginal = False
debugBlack = True
debugGreen = True
debugBlue = False
debugHori = False
record = False
noise_blob_threshold = 16
min_square_size = 150
min_line_size =1000
fixed_angle_value = 0
fixed_angle_active = False
fixed_angle_start_time = 0
estado='esperando'

vs = WebcamVideoStream(src=0).start()
ser = serial.Serial('/dev/serial0', 115200)
lower_black = np.array([0, 0,0])  # BGR
upper_black = np.array([90, 90, 90])
lower_green = np.array([120,90, 100])  # lab
upper_green = np.array([170,120, 140])
lower_silver_hsv = np.array([ 79, 16, 46])  # Valores en espacio HSV para detectar el plateado
upper_silver_hsv = np.array([168, 28, 79])  # Ajusta estos valores si es necesario
lower_red = np.array([1, 147,159])
upper_red = np.array([7, 205, 216])
last_angles = []

test_frame = vs.read()

width, height = 160, 120
print(width, height)

cam_x = width / 2 - 1   # 79 ~ middle column
cam_y = height - 1      # 119 ~ bottom row

timer_active = False
green_output_duration = 1
green_output_cooldown_duration = 2
green_state_final = 0
timer_active = False
timer_start_time = 0
silver_line= False
# GET X AND Y ARRAYS
# scaled by frame dimensions, use this for filtering pixels
x_com = np.zeros(shape=(height, width))
y_com = np.zeros(shape=(height, width))

for i in range(height):
    for j in range(width):
        x_com[i][j] = (j - cam_x) / (width / 2)   # [-1, 1]
        y_com[i][j] = (cam_y - i) / height        # [0, 1]
def modo_rescate():
    global last_target_box
    last_target_box = None  
    global is_stopped  
    global estado, ser
    stop_rescate = False
    import cv2
    if hasattr(cv2, "legacy") and hasattr(cv2.legacy, "TrackerMOSSE_create"):
        print("Legacy MOSSE disponible")
    else:
        print("Legacy MOSSE NO disponible")
    try:
        tr = cv2.legacy.TrackerMOSSE_create() if hasattr(cv2, "legacy") else cv2.TrackerMOSSE_create()
        print("Creado ok:", type(tr))
    except Exception as e:
        print("fallo:", e)

    import os
    os.environ["OMP_NUM_THREADS"] = str(max(1, (os.cpu_count() or 4) - 1))
    os.environ["MKL_NUM_THREADS"] = os.environ["OMP_NUM_THREADS"]

    import time
    import threading
    import queue
    import numpy as np
    from ultralytics import YOLO
    import math

    # ---- CONFIG ----
    MODEL_PATH = "/home/iita/Desktop/zonasdepositoalta.onnx"
    CLASS_NAMES = ['negro', 'plateado', 'rojo alto', 'verde_alto']
    SCORE_THRESHOLD = 0.45
    IMGSZ = 256
    DETECT_EVERY = 1
    MAX_QUEUE = 2
    DRAW_EVERY = 1
    HEADLESS = False

    # ---- cargar modelo ----
    print("Loading model:", MODEL_PATH)
    model = YOLO(MODEL_PATH, task='detect')
    print("Modelo cargado.")
    last_target_box = None
    CENTER_TOLERANCE_PX = 10
    STOP_WIDTH_RATIO = 0.20
    STOP_WIDTH_RATIO_BOX = 0.93
    red_deposited=False
    green_deposited=False
    RESUME_WIDTH_RATIO = 0.18
    is_stopped = False

    def make_mosse():
        """try:
            if hasattr(cv2, "legacy") and hasattr(cv2.legacy, "TrackerMOSSE_create"):
                return cv2.legacy.TrackerMOSSE_create()
        except Exception:
            pass
        try:
            if hasattr(cv2, "TrackerMOSSE_create"):
                return cv2.TrackerMOSSE_create()
        except Exception:
            pass
        try:
            if hasattr(cv2, "Tracker_create"):
                return cv2.Tracker_create("MOSSE")
        except Exception:
            pass"""
        return None

    class CentroidTracker:
        def __init__(self, max_lost=5):
            self.next_object_id = 0
            self.objects = {}
            self.lost = {}
            self.max_lost = max_lost

        def register(self, bbox):
            oid = self.next_object_id
            self.next_object_id += 1
            self.objects[oid] = bbox
            self.lost[oid] = 0
            return oid

        def deregister(self, oid):
            if oid in self.objects: del self.objects[oid]
            if oid in self.lost: del self.lost[oid]

        def update(self, detections):
            if len(detections) == 0:
                remove = []
                for oid in list(self.lost.keys()):
                    self.lost[oid] += 1
                    if self.lost[oid] > self.max_lost:
                        remove.append(oid)
                for oid in remove: self.deregister(oid)
                return [{'id': oid, 'bbox': self.objects[oid]} for oid in self.objects]

            if len(self.objects) == 0:
                for d in detections: self.register(d)
                return [{'id': oid, 'bbox': bbox} for oid, bbox in self.objects.items()]

            object_ids = list(self.objects.keys())
            object_bboxes = [self.objects[oid] for oid in object_ids]

            def centroid(b):
                x1,y1,x2,y2 = b
                return ((x1+x2)//2, (y1+y2)//2)

            obj_centroids = [centroid(b) for b in object_bboxes]
            det_centroids = [centroid(d) for d in detections]

            D = []
            for oc in obj_centroids:
                row = []
                for dc in det_centroids:
                    dx = oc[0]-dc[0]; dy = oc[1]-dc[1]
                    row.append(dx*dx + dy*dy)
                D.append(row)

            matched_obj = set()
            matched_det = set()
            assignments = {}
            triples = []
            for i in range(len(D)):
                for j in range(len(D[0])):
                    triples.append((i,j,D[i][j]))
            triples.sort(key=lambda x: x[2])
            for i,j,_ in triples:
                if i in matched_obj or j in matched_det: continue
                matched_obj.add(i); matched_det.add(j); assignments[i] = j

            for i,j in assignments.items():
                oid = object_ids[i]
                self.objects[oid] = detections[j]
                self.lost[oid] = 0

            for j in range(len(detections)):
                if j not in matched_det:
                    self.register(detections[j])

            for i in range(len(object_ids)):
                if i not in assignments:
                    oid = object_ids[i]
                    self.lost[oid] += 1
                    if self.lost[oid] > self.max_lost:
                        self.deregister(oid)

            return [{'id': oid, 'bbox': bbox} for oid, bbox in self.objects.items()]

    frame_q = queue.Queue(MAX_QUEUE)
    result_q = queue.Queue(MAX_QUEUE)
    stop_event = threading.Event()

    def scale_box(box_xyxy, src_w, src_h, in_w=IMGSZ, in_h=IMGSZ):
        x1, y1, x2, y2 = box_xyxy
        scale_x = src_w / in_w
        scale_y = src_h / in_h
        return int(x1 * scale_x), int(y1 * scale_y), int(x2 * scale_x), int(y2 * scale_y)

    def capture_thread():
        while not stop_event.is_set():
            frame = vs.read()
            ret = frame is not None
            frame = cv2.rotate(frame, cv2.ROTATE_180)
            if not ret:
                frame_q.put(None)
                break
            frame_q.put(frame)
        frame_q.put(None)

    CLASS_THRESH = {

        0: 0.45,  # negro
        1: 0.45,  # plateado
        2: 0.2,  # rojo alto
        3: 0.6   # verde_alto
    }

    CLASS_COLORS = {

        0: (0,0,0),       # negro
        1: (192,192,192), # plateado
        2: (0,100,255),   # rojo alto
        3: (0,255,100)    # verde alto
    }

    def infer_thread():
        frame_idx = 0
        while True:
            frame = frame_q.get()
            if frame is None:
                result_q.put(None)
                break
            h, w = frame.shape[:2]
            small = cv2.resize(frame, (IMGSZ, IMGSZ))
            if frame_idx % DETECT_EVERY == 0:
                results = model.predict(
                    small, imgsz=IMGSZ, conf=min(CLASS_THRESH.values()),
                    iou=0.45, stream=False, verbose=False
                )
                detections = []
                for res in results:
                    for box in res.boxes:
                        score = float(box.conf[0])
                        cls_id = int(box.cls[0])
                        if score < CLASS_THRESH.get(cls_id, 0.5):
                            continue
                        xyxy = box.xyxy[0].cpu().numpy() if hasattr(box.xyxy[0], "cpu") else np.array(box.xyxy[0])
                        x1,y1,x2,y2 = scale_box(xyxy, w, h, IMGSZ, IMGSZ)
                        if estado == "rescate":
                                                  
                            if cls_id in (2, 3):
                                continue
                        if estado =="depositar":
                            if cls_id in (0, 1,2):
                                    continue

                        if estado=="depositar verde":
                            if cls_id in (0, 1, 3):
                                continue

                        detections.append({'xyxy': (x1,y1,x2,y2), 'score': score, 'cls': cls_id})
                result_q.put(('det', frame, detections))
            else:
                result_q.put(('no_det', frame, None))
            frame_idx += 1
    def select_target_from_list(boxes, estado):
            targets = []

            if estado == 'rescate':
                for d in boxes:
                    # bolas: 0 roja, 1 verde
                    if d['cls'] in (0, 1):
                        targets.append(d)

            if estado == 'depositar':
                for d in boxes:
                    if d['cls'] in (3,):   # zonas red + green
                        targets.append(d)
            if estado=="depositar verde":
                for d in boxes:
                    if d['cls'] in (2,):   # zonas red + green
                        targets.append(d)
            if not targets:
                return None

            return targets[0]

    def choose_stable_target(detections, last_target,estado):
        if not detections:
            return None
        if last_target is None:
            return select_target_from_list(detections,estado)
        lx = (last_target['xyxy'][0] + last_target['xyxy'][2]) // 2
        ly = (last_target['xyxy'][1] + last_target['xyxy'][3]) // 2
        best = None
        best_dist = 1e12
        for d in detections:
            cx = (d['xyxy'][0] + d['xyxy'][2]) // 2
            cy = (d['xyxy'][1] + d['xyxy'][3]) // 2
            dist = math.hypot(cx - lx, cy - ly)
            if dist < best_dist:
                best = d
                best_dist = dist
        return best

    serial_stop_evt = threading.Event()
    def serial_monitor_local():
        nonlocal stop_rescate
        global estado   # <-- necesario para modificar la variable global
        while not serial_stop_evt.is_set():
            try:
                if ser.in_waiting > 0:
                    data = ser.read()

                    if data == b'\xff':
                        print("serial monitor ")
                        stop_rescate = True
                        estado = 'esperando'
                        break
                    if data == b'\xf8' and estado=="rescate":   # 248
                        print("Llego 248 -> terminar rescate y cambiar a depositar")
                        estado = 'depositar'

            except Exception as e:
                print("serial_monitor_local error:", e)
            time.sleep(0.01)


    t_serial_mon = threading.Thread(target=serial_monitor_local, daemon=True)
    t_serial_mon.start()

    def main_loop():
        global last_target_box
        global is_stopped
        global estado
        processed = 0
        start = time.time()

        mosse_available = (make_mosse() is not None)
        if mosse_available:
            print("Usando MOSSE de OpenCV (legacy).")
        else:
            print("MOSSE no disponible: usando CentroidTracker fallback.")
        centroid_tracker = CentroidTracker(max_lost=5)
        trackers = []
        last_detections = []

        while True:
            if stop_rescate:
                print("main_loop: stop_rescate activo -> saliendo de rescate")
                break

            try:
                item = result_q.get(timeout=0.25)
            except queue.Empty:
                continue

            if item is None:
                break
            typ, frame, detections = item

            if typ == 'det':
                last_detections = detections or []
                if mosse_available:
                    trackers = []
                    for d in last_detections:
                        x1,y1,x2,y2 = d['xyxy']
                        w = x2 - x1; h = y2 - y1
                        if w <= 0 or h <= 0: continue
                        trk = make_mosse()
                        if trk is None: continue
                        ok = trk.init(frame, (x1,y1,w,h))
                        if ok: trackers.append({'tracker': trk, 'cls': d['cls'], 'score': d['score']})
                else:
                    bboxes = [d['xyxy'] for d in last_detections]
                    ct_objs = centroid_tracker.update(bboxes)
                    new_list = []
                    for obj in ct_objs:
                        bx = obj['bbox']
                        best = None; best_dist = 1e12
                        for d in last_detections:
                            cx = (d['xyxy'][0]+d['xyxy'][2])//2
                            cy = (d['xyxy'][1]+d['xyxy'][3])//2
                            ox = (bx[0]+bx[2])//2
                            oy = (bx[1]+bx[3])//2
                            dx = cx-ox; dy = cy-oy; dd = dx*dx+dy*dy
                            if dd < best_dist: best_dist = dd; best = d
                        if best is not None:
                            new_list.append({'xyxy': bx, 'cls': best['cls'], 'score': best['score']})
                        else:
                            new_list.append({'xyxy': bx, 'cls': 0, 'score': 0.0})
                    last_detections = new_list

            else:  # no_det
                if mosse_available:
                    updated = []
                    for t in trackers:
                        ok, bbox = t['tracker'].update(frame)
                        if not ok: continue
                        x, y, w, h = map(int, bbox)
                        updated.append({'xyxy': (x, y, x+w, y+h), 'cls': t['cls'], 'score': t.get('score',0.0)})
                    last_detections = updated
                else:
                    ct_objs = centroid_tracker.update([])
                    last_detections = []
                    for obj in ct_objs:
                        last_detections.append({'xyxy': obj['bbox'], 'cls': 0, 'score': 0.0})

            target = choose_stable_target(last_detections, last_target_box, estado)

            last_target_box = target

            STOP_RATIO = 0.3
            green_state=0
            speed = 0
            angle = 0

            if target:
                x1, y1, x2, y2 = target['xyxy']
                cx = (x1 + x2) // 2
                cy = (y1 + y2) // 2
                bbox_w = x2 - x1
                bbox_h = y2 - y1
                area = bbox_w * bbox_h
                frame_w = frame.shape[1]

                error_x = cx - (frame_w // 2)
                error_norm = error_x / (frame_w // 2)

                centered = abs(error_x) < CENTER_TOLERANCE_PX
                width_ratio = bbox_w / float(frame_w)
                cv2.putText(frame, f"w_ratio={width_ratio:.3f}", (10,50),
                            cv2.FONT_HERSHEY_SIMPLEX, 0.6, (255,255,255), 1)
                if estado=="depositar" or estado=="depositar verde":
                    close_enough = width_ratio >= STOP_WIDTH_RATIO_BOX
                else:
                    close_enough = width_ratio >= STOP_WIDTH_RATIO

                resume_close = width_ratio >= RESUME_WIDTH_RATIO

                if close_enough:
                    speed = 5
                    if not centered:
                        angle = int(-error_norm * 90)
                    else:
                        angle = 0
                        speed=0
                        ball_type = None
                        if target['cls'] == 0:
                            ball_type = "silver"
                        elif target['cls'] == 1:
                            ball_type = "black"
                        elif target['cls'] == 2:
                            ball_type = "red_zone"
                        elif target['cls'] == 3:
                            ball_type = "green_zone"
                        if ball_type == "silver":
                            green_state = 6
                        elif ball_type == "black":
                            green_state = 7
                        elif ball_type == "red_zone":
                            green_state = 8
                        elif ball_type == "green_zone":
                            green_state = 9
                            estado="depositar verde"
                    if not is_stopped:
                        angle = 0
                        speed=0
                        ball_type = None
                        if target['cls'] == 0:
                            ball_type = "silver"
                        elif target['cls'] == 1:
                            ball_type = "black"
                        elif target['cls'] == 3:
                            ball_type = "green_zone"
                        elif target['cls'] == 2:
                            ball_type = "red_zone"
                        if ball_type == "silver":
                            green_state = 6
                        elif ball_type == "black":
                            green_state = 7
                        elif ball_type == "red_zone":
                            green_state = 8
                        elif ball_type == "green_zone":
                            green_state = 9
                            estado="depositar verde"

                        print(f"[STOP] width_ratio={width_ratio:.3f}, bbox_w={bbox_w}, frame_w={frame_w}")
                    is_stopped = True
                else:
                    is_stopped = False
                    angle = int(-error_norm * 90)
                    speed = int(20 * (1 - abs(error_norm)))
                    speed = min(speed, 20)

                if processed % DRAW_EVERY == 0:
                    color = CLASS_COLORS.get(target['cls'], (0, 255, 255))
                    cv2.rectangle(frame, (x1, y1), (x2, y2), color, 2)
                    cv2.circle(frame, (cx, cy), 5, (0,0,255), -1)
                    cv2.line(frame, (frame.shape[1]//2, 0),
                             (frame.shape[1]//2, frame.shape[0]), (255,0,0), 1)
                    cv2.putText(frame,
                                f"{CLASS_NAMES[target['cls']]} {target.get('score',0):.2f} w={bbox_w}",
                                (x1, y1-6),
                                cv2.FONT_HERSHEY_SIMPLEX, 0.5, color, 2)
            else:
                speed = 10
                angle = 90
                green_state=0

            output = [255, speed, 254, angle + 90, 253, green_state, 252, 0]
            ser.write(output)
            print(output)
            processed += 1
            elapsed = time.time() - start
            fps = processed / elapsed if elapsed>0 else 0.0
            cv2.putText(frame, f"FPS: {fps:.2f}", (10,30), cv2.FONT_HERSHEY_SIMPLEX, 0.8, (0,255,0), 2)

            if not HEADLESS:
                cv2.imshow("Optimizado", frame)
                if cv2.waitKey(1) & 0xFF == ord('q'):
                    stop_event.set(); break
            else:
                if processed % 30 == 0:
                    print(f"[HEADLESS] FPS ~ {fps:.2f}  detecciones: {len(last_detections)}")

        if not HEADLESS:
            cv2.destroyAllWindows()

    # ---- lanzar hilos ----
    tcap = threading.Thread(target=capture_thread, daemon=True)
    tinf = threading.Thread(target=infer_thread, daemon=True)
    tcap.start(); tinf.start()
    try:
        main_loop()
    finally:
        stop_event.set()
        serial_stop_evt.set()
        stop_rescate = False
        tcap.join(timeout=1)
        tinf.join(timeout=1)
        t_serial_mon.join(timeout=0.5)
while True:

    while estado == 'esperando':
        frame = vs.read()
        silver_line=False
        if ser.in_waiting > 0:
            data = ser.read()
            if data == b'\xf9':
                estado = 'linea'
            ser.reset_input_buffer()

    while estado =='rescate':
        modo_rescate()

    while estado == 'linea':

        frame = vs.read()
        frame = cv2.rotate(frame, cv2.ROTATE_180)
        frame_resized = cv2.resize(frame, (160, 120), interpolation=cv2.INTER_NEAREST)
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

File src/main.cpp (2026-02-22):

#include <Wire.h>
#include <Arduino.h>
#include <drivebase.h>
#include <PID.h>
#include <elapsedMillis.h>
#include <Adafruit_Sensor.h>
#include <Adafruit_BNO055.h>
#include "math.h"
#include <Servo.h>
#include <Adafruit_I2CDevice.h>
#include <claw.h>
#include "Adafruit_APDS9960.h"
#include <NewPing.h>
#include <Wire.h>
#include <VL53L0X.h>



// SERVOS
DFServo sort(23, 540, 2390, 274);
DFServo left(14, 540, 2390, 274);
DFServo right(15, 540, 2390, 274);
DFServo lift(22, 540, 2390, 274);
DFServo deposit(12, 540, 2390, 274);
Claw claw(&lift, &left, &right, &sort, &deposit);

// CONSTANTS //
#define FORWARD 0         // Def direction ADELANTE
#define BACKWARD 1        // Def direction ATRAS
#define RELAY 0
#define BUZZER 35         // Definicion de PIN BUZZER
#define LED_ROJO 34       // Definicion de PIN LED_ROJO
#define SWITCH 32         // Definicion de PIN SWITCH
elapsedMillis steertimer; // Cuenta el tiempo transcurrido
bool contador = false;    // Para saber si estamos contando el tiempo o no
bool retroceder = false;  // Para saber si debe retroceder
// INITIALISE BNO055 //
Adafruit_BNO055 bno = Adafruit_BNO055(55, 0x28);
// INITIALISE ACTUATORS //
Moto bl(29, 28, 27, "BL"); // pwm, dir, enc
Moto fl(7, 6, 5, "FL");
Moto br(36, 37, 38, "BR");
Moto fr(4, 3, 2, "FR");
DriveBase robot(&fl, &fr, &bl, &br);
// STATE VARIABLES & FLAGS //
String color_detected;
unsigned long tiemporescate=0;
static unsigned long lastTurn = 0;           // persiste entre iteraciones
const unsigned long turnCooldown = 600;      // ms (ajusta)
int counter = 0;
int laststeer = 0;
int serial5state = 0;  // serial code e.g. 255
double speed;          // speed (0 to 100)
double steer;          // angle (0 to 180 deg, will -90 later)
int green_state = 0;   // 0 = no green squares, 1 = left, 2 = right, 3 = double
int silver_line = 0;   // if there is a line to reacquire after obstacle
int servo = 0;
int action =7;            // action to take (part of a task)
bool taskDone = false; // if true, update current_task
int angle0;            // initial IMU reading
bool startUp = false;
float frontUSReading;
int RanNumber;
String rutina = "linea";
bool first_rescate = 1;
String wall = "right";
bool esquinas_negro[3];
bool final_rescate = 1;
String lado_plateado="";
bool lectura =0;
int cccounter,
    leftLidarReading, rightLidarReading;
VL53L0X left_tof;  // Sensor 1
VL53L0X right_tof; // Sensor 2
int distance_left_tof;
int distance_right_tof;
float angulo_rescate = 0;
float centrar = 0;
String pared="";
bool alineado=false;
bool depositando=false;
int veces_deposit=2;
int ball_counter=2;
#define SONAR_NUM 3      // Number of sensors.
#define MAX_DISTANCE 150 // Maximum distance (in cm) to ping.

NewPing sonar[SONAR_NUM] = {     // Sensor object array.
    NewPing(8, 9, MAX_DISTANCE), // Each sensor's trigger pin, echo pin, and max distance to ping.
    NewPing(11, 10, MAX_DISTANCE),
    NewPing(39, 33, MAX_DISTANCE)};

int front_distance;
int left_distance;
int right_distance;

// -----------  FUNCTIONS  -----------
// ULTRASONIDOS FRENTE IZQ DER
void leer_ultrasonidos()
{
    front_distance = sonar[0].ping_cm();
    left_distance = sonar[1].ping_cm();
    right_distance = sonar[2].ping_cm();
}

void imprimir_ultrasonidos()
{
    Serial.print("|D: ");
    Serial.print(right_distance);
    //Serial.println("cm ");
}

// TOF
void leer_tof()
{
    distance_left_tof = left_tof.readRangeContinuousMillimeters();
    distance_right_tof = right_tof.readRangeContinuousMillimeters();
}

void imprimir_tof()
{
    Serial.print("Distance Left: ");
    Serial.print(distance_left_tof);
    Serial.print("mm");

    if (left_tof.timeoutOccurred())
    {
        Serial.print(" TIMEOUT");
    }

    Serial.print("   Distance Right: ");
    Serial.print(distance_right_tof);
    Serial.print("mm");

    if (right_tof.timeoutOccurred())
    {
        Serial.print(" TIMEOUT");
    }
}
void reset_enconder(){
    bl.resetPulseCount();
    fl.resetPulseCount();
    br.resetPulseCount();
    fr.resetPulseCount();
}
// Color Sensor
Adafruit_APDS9960 apds;
struct Color
{
    String name;
    uint16_t r, g, b, c;
};

Color known_colors[] = {
  {"Rojo", 12, 5, 7, 24},
  {"Negro", 0, 0, 0, 67},
  {"Verde", 3, 7, 7, 19},
  
  };
// Función para leer los valores del sensor y determinar el color
String get_color()
{
    uint16_t r, g, b, c;

    // Esperar a que los datos de color estén listos
    while (!apds.colorDataReady())
    {
        delay(5);
    }

    // Obtener los datos del sensor
    apds.getColorData(&r, &g, &b, &c);

    // Calcular el color más cercano utilizando mínimos cuadrados
    String closest_color = "Desconocido";
    uint32_t min_error = UINT32_MAX;

    for (size_t i = 0; i < sizeof(known_colors) / sizeof(known_colors[0]); i++)
    {
        uint32_t error = pow(known_colors[i].r - r, 2) +
                         pow(known_colors[i].g - g, 2) +
                         pow(known_colors[i].b - b, 2) +
                         pow(known_colors[i].c - c, 2);
        if (error < min_error)
        {
            min_error = error;
            closest_color = known_colors[i].name;
        }
    }

    // Imprimir los valores de R, G, B y Clear
    /*
    Serial.print("red: ");
    Serial.print(r);
    Serial.print(" green: ");
    Serial.print(g);
    Serial.print(" blue: ");
    Serial.print(b);
    Serial.print(" clear: ");
    //Serial.println(c);
    */

    return closest_color;
}

// ISR for updating motor pulses
void ISR1() { bl.updatePulse(); }
void ISR2() { fl.updatePulse(); }
void ISR3() { br.updatePulse(); }
void ISR4() { fr.updatePulse(); }

// Read Data from Raspberry by Serial TX-RX
void serialEvent5()
{
    if (Serial5.available() > 0)
    {
        int data = Serial5.read(); // read serial code
         
        if (data == 255) // speed incoming
            serial5state = 0;
        else if (data == 254) // steer incoming
            serial5state = 1;
        else if (data == 253) // task incoming
            serial5state = 2;
        else if (data == 252) // line_middle incoming
            serial5state = 3;
        else if (serial5state == 0)           // set speed
            speed = (double)data / 100 * 100; // max speed = 100
        else if (serial5state == 1)           // set steer
            steer = ((double)data - 90) / 90;
        else if (serial5state == 2) // set task
            green_state = data;
        else if (serial5state == 3) // set line_middle
            silver_line = data;
    }
}

// HELPER FUNCTIONS //
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

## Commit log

2024-05-11 agrego switch sistema de encendido
2024-05-11 muevo libreria del sensor
2024-05-11 cambio pequeño en modulo de la linea negra
2024-05-16 con los archivos para impirimir en stl
2024-05-16 con los archivos para imprimir en stl
    [Aleta(izquierda).stl, Aleta.stl, BASE CAJITA.stl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]
2024-05-17 con el boceto subido, y lista de videos de fusion
2024-05-18 cambio en el modulo de linea negra
2024-05-18 agrego el while true en el modulo de linea negra
2024-05-18 agrego el modulo de la zona de rescate
2024-05-23 Todavía me faltan los tamaños de los tornillos
    [SERVOS_def.stl, cajón_servo.stl]
2024-05-25 Con las medidas de los tornillos (aprox)
2024-05-30 ya está la lista con los cambios subidos
    [Motor_L_corregido.stl, SERVOS_def.stl, Servos_corregido.stl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]
2024-06-02 README_Comunicacion Raspberry y Teensy
2024-06-03 README_Raspberry y Teensy
2024-06-04 Ya está subido el estado de situación de las piezas
    [SERVOS_def.stl, SoprteMotorOmnidireccional.stl]
2024-06-08 Readme del funcionamiento de las librerias
2024-06-22 Diseño 3d Actualizado
    [Tubitos_6diam.stl, Tubitos_juntos.stl, tubo.stl]
2024-07-20 correcion de un par de pines
2024-10-05 pruebas de color y pared
2025-10-12 Update main.cpp
    Ultimpo programa antes de la bateria
2026-02-17 eliminar cosas raspberry
2026-02-17 Main Raspberry
2026-02-22 Agregar backups
    [Aleta(izquierda).stl, Aleta.stl, BASE CAJITA.stl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]
2026-02-22 Update YOLO y Raspberry.md
2026-02-22 YOLO y Raspberry.md
2026-02-22 Lista de materiales y link de compra.md
